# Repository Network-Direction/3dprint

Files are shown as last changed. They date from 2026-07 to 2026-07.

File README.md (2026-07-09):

# 3dprint
My repository of 3d printing information and models.

This is focused on the Ender 3 v3, but would be helpful for other printers too.

</br></br>
## Klipper

Information about using Klipper, including how to connect a Raspberry Pi to the printer, and flash it with Klipper firmware.

</br></br>
## Calibration

Calibrating and tuning Klipper settings for the best prints.

</br></br>
## Macros

Macros used in Klipper or Octoprint.

</br></br>
## Models

Useful models, including Autodesk Fusion source files.

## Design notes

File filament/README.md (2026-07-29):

# Filament Guides

This section includes settings for various filaments I have used, that I have found useful.

These can be a guide to get started, but should not be a replacement for [proper calibration](../calibration).

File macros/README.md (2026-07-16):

# Macros

Macros are a script of g-code to run common commands. For example:
* Commands to run before a print job
* Commands to run after a job completes
* Extrude a test line before starting
* Load or unload filament

</br></br>
---
## Calling Macros from Orca

Macros can be called automatically by referring to them in the gcode. This means the slicer needs to be aware of the macros so it can embed these commands.

In Orca slicer, edit the printer settings, and go to the **Machine G-code** tab.

This contains an area when you can add custom G-code at various points of the print. The two most useful ones are:
* Machine start G-code
* Machine end G-code

</br></br>
These areas run specific commands every time a job starts and ends.

In **Machine start G-code**, replace anything that's already there with:

```gcode
SET_PRINT_STATS_INFO TOTAL_LAYER_COUNT=[total_layer_count]
START_PRINT BED_TEMP=[first_layer_bed_temperature] EXTRUDER_TEMP=[first_layer_temperature]
```

</br></br>
This adds some useful information to the gcode file about the print, such as the total layer count.

The second line is the important one. This calls the [`START_PRINT`](print_start.cmd) macro, and passes the bed and extruder temperature.

> [!WARNING]
> Make sure these macros exist in mainsail if you're going to use them.

</br></br>
In **Machine end G-code**, replace anything that's already there with:

```gcode
END_PRINT
```

</br></br>
This simply calls the [`END_PRINT`](print_end.cmd) macro at the end of a print job.

</br></br>
---
## Macro File

Macros can be placed directly in `printer.cfg`, but it is recommended to put them in a separate file, `macros.cfg`.

The `printer.cfg` file should 'include' this extra file.

```ini
[include macros.cfg]
```

</br></br>


Mainsail includes a macro section on the dashboard containing any macros that have been defined.

These include the ones in `macro.cfg`, as well as some predefined ones from `mainsail.cfg`.

</br></br>
---
## Macro Format

### Starting a Macro

Macros all start with a line like this:

```ini
[gcode_macro MACRO_NAME]
```

This identifies the following code as being a macro, as well as giving it a name.

</br></br>
All macros must also have a line like this:

```gcode
gcode:
  ; Commands
```

This defines the start of the g-code. Commands listed under this must be indented (similar to a YAML file).

</br></br>
### Macro Code

Code within the macro can be:
* Jinja2 template code
* G-code
* Klipper commands
* Calls to other macros

For example, this clears the current state (a klipper command), and then heats the print bed:

```gcode
[gcode_macro EXAMPLE]
gcode:
    CLEAR_PAUSE         ; Klipper command
    M190 S60            ; gcode
```

</br></br>
### Arguments

Arguments can be provided to macros. For example, if we want to preheat the extruder, we can include a temperature to preheat it to.

This is done using a combination of jinja2 and `params`.

```gcode
[gcode_macro PREHEAT]
gcode:
    {% set extruder_temp = params.TEMP | default(220) | float %}
    M104 S{extruder_temp}
```

</br></br>
In this example we can see:
* The macro takes an argument called `TEMP`
* This is an optional argument, as it has a default value
* The datatype for the argument is a `float`
* This value is assigned to the `extruder_temp` variable
* The `M104` command uses the `extruder_temp` variable to preheat the extruder

</br></br>
To use arguments, call a macro like this:

```ini
PREHEAT TEMP=200
```

</br></br>
This calls a macro caled `PREHEAT`, and passes the value `200` as the `TEMP` argument.

</br></br>
### Flow Control and Variables

Flow control, like if, then, else, as well as looping, can be implemented using Jinja2.

Variables can be defined before the `gcode` area, or set within the `gcode` area using jinja templates.

```gcode
[gcode_macro HELLO_BED]
variable_greeting_temp: 40      # Variable set BEFORE gcode:
gcode:
    {% set bed_temp = printer.heater_bed.temperature %}   ; Variable set WITHIN gcode:

    {% if bed_temp > greeting_temp %}
        { action_respond_info("Bed is warm!") }
    {% else %}
        { action_respond_info("Bed is cool.") }
    {% endif %}
```

The example above:
* Sets a variable called `variable_greeting_temp` and sets it to 40
* Gets the current bed temperature, and assigns it to the `bed_temp` variable
* Uses an if/else block to print a message based on the bed temperature

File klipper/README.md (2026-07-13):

# Klipper Guide

The files in this section contain the guide to setup your printer with Klipper, and to connect a slicer to it.

Start with [the Klipper guide](klipper.md) and then move on to [the slicer configuration](orca_setup.md).

Optionally you can use [the slicer settings](slicer_settings.md) that I have created, or use your own.

You may also want to try to [restore the LCD screen functionality](ender_screen.md) after the update.

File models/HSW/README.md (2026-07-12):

# Honeycomb Storage Wall (HSW)

This is a collection of models and files related to the project found here: [https://makerworld.com/en/models/22521-honeycomb-storage-wall]

> [!WARNING]
> Be sure to get the tolerance of the printer right before printing any of the wall parts.
>
> If the tolerance is not right, the socket inserts may not fit into the wall correctly. They would need to be scaled down slightly.

</br></br>
---
## Files

Files are available in various formats.

| File Type | Usage |
| --- | --- |
| stl | The raw model. Will need to be added to a slicer |
| 3mf | A slicer project file. Uses settings suitable for an Ender 3  |
| f3d | An Autodesk Fusion file. So you can edit the designs yourself |

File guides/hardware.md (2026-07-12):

# Hardware

## Nozzle HRC

HRC is the Rockwell Hardness Scale. This measures the hardness of metal materials.

Different nozzles are needed depending on the abrasiveness of the filament. More abrasive filaments will wear down softer nozzles faster.

</br></br>
| Value | Nozzle Type | Filament Type |
| ----- | --- | --- |
| 0 | Brass | PLA, PETG |
| 1 | Coated | Wood filled PLA, Glow in the dark PLA |
| 2 | Hardened Steel | Carbon fiber, metal filled filaments  |
| 3 | Hardened Steel (HRC 60+) | Carbon fiber, metal filled filaments  |

</br></br>
This is set in the filament profile in the slicer, so the slicer knows what nozzle is required. If you use a printer with a softer nozzle, it will warn you about this before you proceed.

A value of zero means this will not be checked.

</br></br>
> [!NOTE]
> Changing this setting will not improve performance or quality. It simply enables your slicer to warn you if needed.

</br></br>
---
## Fans (Ender 3 v3)

The Ender 3 has a total of four fans:
* Hot end cooling fan
* Part cooling fan
* Motherboard fan
* PSU fan

</br></br>
> [!WARNING]
> The Ender uses 24v for fans. Make sure any replacement is 24v as well.
>
> Alternatively, use a 12v fan (quieter) with a _buck converter_ to convert the 24v to 12v.

</br></br>
### Hot End Cooling Fan

This fan is in the extruder, and turns on when printing starts.

It is a 24v 4010 axial fan (40x40x10mm), with 2-pin 1.35mm JST header. 2-pin means there's no PWM, so no control over fan speed. It is on or off.

</br></br>
Good options seem to include:
* Noctua NF-A4x10 FLX (12v, requires buck converter)
* Sunon 4020

</br></br>
### Part Cooling Fan

This is also housed in the extruder. This is PWM controlled, so the printer can control the fan speed.

This is a 24v blower/radial fan, with 1.25mm JST headers. This is still a 2-pin connector. The motherboard uses PWM to control the speed.

Because of the PWM control, any replacement should also be 24v, not 12v with a buck converter.

Typically a new fan shroud would be needed.

</br></br>
> [!WARNING]
> Due to the heat produced, this should be printed in PETG, not PLA.

</br></br>
### Motherboard Fans

This is for cooling the stepper motor drivers. This is a 6015 axial fan (60x60x15mm), at 24v.

Quiet fans to replace this are rare, so the alternative is to adapt the base cover of the printer, and include a larger quiet 12v fan with a buck converter.

</br></br>
### PSU Fan

This is also a 6015 24v axial fan. This keeps the power supply cool. It usually kicks in when the bed warms up.

</br></br>
> [!WARNING]
> Be careful when modifying anything related to the PSU. There is a risk of electrical shock.

</br></br>
Modifying this directly has risks, and voids warranty.

An alternative is to print a new shroud for the PSU, and use large quiet PC fans. These move a lot more air at a lower dB.

</br></br>
### References

https://www.reddit.com/r/ender3/comments/gkkli3/quieting_my_ender_3_pro/

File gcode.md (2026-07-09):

# G Code

## Overview

The programming language that tells the printer what to do. This is similar to assembly code in some ways.

This is the language of machines in general, such as CNC machines, laser cutters, and engravers. It's not just for 3d printers.

You don't generally need to write your own g-code. However, knowing the basics helps when it comes to using macros, and sometimes with troubleshooting.

> [!NOTE]
> There are some differences in gcode between CNC machines and 3d printers.
> This article is only for 3d printers.

</br></br>
### Commands
G-codes start with a letter like 'G' or 'M'.

Some commands take an extra parameter, which also starts with a letter. For example, `M104 S210`

</br></br>
### Parameters

Letters like 'S', 'T', 'V', and others are used as arguments to a command to set values.

For example, in `M104 S210`, the 'm104' part is the command to heat the nozzle. The 'S210' is the temperature to set it to.

Here are some of the letters and what they are for. The 'name' is sometimes historical, and doesn't always accurately represent the use on a 3d printer.

</br></br>
| Letter | Name | Usage |
| --- | --- | --- |
| S | Speed | Sets temperatures or fan speeds |
| X | Coordinate | An X target coordinate |
| Y | Coordinate | A Y target coordinate |
| Z | Coordinate | A Z target coordinate |
| F | Feedrate | Usually the speed the print head moves at |
| E | Extrude | Used with extruder commands. Defines how much filament to extrude |

</br></br>
## Commands

### Geometric Commands

Geometric commands control the motion and positioning of the printer's nozzle. These commands start with a 'G', and are followed by a number.

</br></br>
#### Move - G0 and G1

These are linear movement commands. It tells the print head where to go, using X, Y, Z coordinates, and what speed to move at. The print head will move there in a straight line.

`G0` is a _rapid move_, while `G1` is a _controlled move_. In modern 3d printing, they functionally the same thing.

</br></br>
**Arguments:**

| Argument | Description |
| --- | --- |
| `X` | The X coordinate posistion |
| `Y` | The Y coordinate posistion |
| `Z` | The Z coordinate posistion |
| `F` | Speed of the print head move in mm/min |
| `E` | The amount of filament to extrude |

</br></br>
Not all coordinates are needed, only the ones that are changing.

</br></br>
**Example**

```gcode
G1 X100 Y50 Z0.2 F1500 E5    ; Move to 100,50,0.2 at a rate of 1500mm/min, and extrude 5mm of filament
```

</br></br>
A negative value on `E` will retract the filament:

```gcode
G1 E-1.0 F2100                ; Retracts 1mm of filament
```

</br></br>
#### Dwell - G4

Pauses the command queue, and waits for a period of time. With no arguments, this is the same as `M400`, which causes g-code processing to pause until all other commands are complete (eg, waits for heating or cooling)

</br></br>
**Arguments:**

| Argument | Description |
| --- | --- |
| `S` | Number of milliseconds to dwell |
| `P` | Number of seconds to dwell |

</br></br>
If both arguments are supplied, `S` will take precedence.

</br></br>
#### Home Position - G28

Tells the printer to move the print head back to the home coordinates.

Often this needs to be done before other operations can be started.

</br></br>
#### Positioning - G90 and G92

`G90` sets absolute positioning mode. This means the printer will move exactly to the given coordinates. It will not move relative to its current position.

`G92` tells the printer to rename the current position as _zero_. This is like telling the printer where to start from.

</br></br>
**Example**

```gcode
G92 E0    ; Reset the extruder's position reference, and extrude nothing
```

</br></br>
### Miscellaneous Commands

These commands are for non-geometric tasks. They all start with the letter 'M', followed by a number.

Some of these commands need to complete before moving to the next command. Others start the command and move on immediately.

</br></br>
#### Relative Mode - M83

Sets the extruder to _relative_ mode. The extruder is also known as the **E-Axis**.

This means each extrusion commands will just extrude the amount of filament they're told to in the instruction, not work on a cumulative total.

</br></br>
#### Disable Motors - M84

Turns the motors off, typically when a print job has been completed.

</br></br>
#### Nozzle Temperature - M104 and M109

Both of these will set the nozzle temperature.

`M104` will set the temperature, and let the printer move on to the next command while the hot end heats up.

`M109` requires the hot end to heat up to the given temperature before the printer moves on to the next command.

</br></br>
**Arguments:**

| Argument | Description |
| --- | --- |
| `S` | The temperature to set |

</br></br>
**Example**

```gcode
M104 S220
```

</br></br>
#### Bed Temperature - M140 and M190

Both set the bed temperature. 

`M140` will set the temperature, and let the printer move on to the next command while the hot end heats up.

`M190` requires the bed to heat up to the given temperature before the printer moves on to the next command.

</br></br>
**Arguments:**

| Argument | Description |
| --- | --- |
| `S` | The temperature to set |

</br></br>
**Example**

```gcode
M104 S220
```

</br></br>
#### Acceleration - M204

Sets the preferred acceleration of the hotend.

</br></br>
#### Cancel Objects - M486

Used to cancel specific items on the print bed. When printing multiple items at once, you may want to cancel one of them without cancelling the entire print job. This command can do this.

To support this, the slicer needs:
* Label Objects:    Enabled
* Exclude Objects:  Enabled

</br></br>
**Arguments:**

| Argument | Description |
| --- | --- |
| `C` | Cancel the current object |
| `P<index>` | Cancel an object with a given index |
| `S<index>` | Set the index of the current object |
| `T<index>` | Reset state and set the number of objects |
| `U<index>` | Un-cancel object with the given index |

</br></br>
### Ignored Commands

The slicer will create a gcode file which is sent to the printer for processing.

The Klipper firmware will ignore some of the codes, as it does not use them.

These include:
* M201
* M203
* M205

</br></br>
---
## References

Gcodes can be found here: [https://marlinfw.org/docs/gcode/G004.html]

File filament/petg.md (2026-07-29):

# PETG Filament Settings

Useful settings I have found. Tested on the Ender 3 v3 SE with unicorn hotend.

> [!WARNING]
> This page is stil in progress

</br></br>
---
## Process Settings

</br></br>
| Tab | Section | Setting | Value |
| --- | --- | --- | --- |
| Quality | Precision | X-Y Hole Compensation | 0.17mm |
| Quality | Precision | X-Y Contour Compensation  | |

</br></br>
| Tab | Section | Setting | Value |
| --- | --- | --- | --- |
| Speed | First Layer Speed  | First layer | 30mm/s |
| Speed | First Layer Speed  | First layer infill | 40mm/s |
| Speed | First Layer Speed  | First layer travel speed  | 100mm/s  |
| Speed | Other Layers Speed | Outer wall | 100mm/s  |
| Speed | Other Layers Speed | Inner wall | 120mm/s  |

</br></br>
---
## Basic PETG

Tested using Bambu Labs Basic PETG.

</br></br>
### Filament Settings

| Tab | Section | Setting | Value |
| --- | --- | --- | --- |
| Filament | Basic | Shrinkage (XY) | 100% |
| Filament | Basic | Shrinkage (Z) | 100% |
| Filament | Basic | Min nozzle temp | 230 |
| Filament | Basic | Max nozzle temp | 260 |
| Filament | Flow and PA | Flow Ratio | 0.93 |
| Filament | Flow and PA | Pressure Advance | Disabled |
| Filament | Print Temp  | Nozzle: First Layer  | 260 |
| Filament | Print Temp  | Nozzle: Other Layers | 245 |
| Filament | Bed Temp | Textured PEI | 80 |
| Filament | Volumetric  | Max vol speed | 14.9 |

</br></br>
| Tab | Section | Setting | Value |
| --- | --- | --- | --- |
| Cooling  | Cooling for Layer | No cooling for first | 3 layers |
| Cooling  | Part Cooling Fan  | Min fan speed threshold | 20% |
| Cooling  | Part Cooling Fan  | Max fan speed threshold | 40% |

</br></br>
| Tab | Section | Setting | Value |
| --- | --- | --- | --- |
| Overrides | Retraction | Length | 1.2mm |

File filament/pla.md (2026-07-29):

# PLA Filament Settings

Useful settings I have found. Tested on the Ender 3 v3 SE with unicorn hotend.

</br></br>
---
## Process Settings

</br></br>
| Tab | Section | Setting | Value |
| --- | --- | --- | --- |
| Speed | First Layer Speed  | First layer | 30mm/s |
| Speed | First Layer Speed  | First layer infill | 40mm/s |
| Speed | First Layer Speed  | First layer travel speed  | 100mm/s  |
| Speed | Other Layers Speed | Outer wall | 140mm/s  |
| Speed | Other Layers Speed | Inner wall | 160mm/s  |

</br></br>
> [!NOTE]
> These next settings will vary per printer. See the [calibration guides](../calibration) to tune them.

</br></br>
| Tab | Section | Setting | Value |
| --- | --- | --- | --- |
| Quality | Line width | First layer | 125% |
| Quality | Precision | X-Y hole compensation | 0.12mm |
| Quality | Precision | X-Y contour compensation  | 0.2mm |
| Quality | Walls and Surfaces | Bottom surface flow ratio | 1.02 |

</br></br>
---
## Basic PLA

Tested using Bambu Labs Basic PLA.

</br></br>
### Filament Settings

| Tab | Section | Setting | Value |
| --- | --- | --- | --- |
| Filament | Basic | Shrinkage (XY) | 100% |
| Filament | Basic | Shrinkage (Z) | 100% |
| Filament | Basic | Min nozzle temp | 190 |
| Filament | Basic | Max nozzle temp | 240 |
| Filament | Flow and PA | Flow Ratio | 0.98 |
| Filament | Flow and PA | Pressure Advance | Disabled |
| Filament | Print Temp  | Nozzle: First Layer  | 220 |
| Filament | Print Temp  | Nozzle: Other Layers | 220 |
| Filament | Bed Temp | Textured PEI | 60 |
| Filament | Volumetric  | Max vol speed | 18.81 |

</br></br>
---
## Matte PLA

Tested using Sunlu Matte PLA.

</br></br>
### Filament Settings

| Tab | Section | Setting | Value |
| --- | --- | --- | --- |
| Filament | Basic | Shrinkage (XY) | 100% |
| Filament | Basic | Shrinkage (Z) | 100% |
| Filament | Basic | Min nozzle temp | 205 |
| Filament | Basic | Max nozzle temp | 245 |
| Filament | Flow and PA | Flow Ratio | 0.97 |
| Filament | Flow and PA | Pressure Advance | Disabled |
| Filament | Print Temp  | Nozzle: First Layer  | 220 |
| Filament | Print Temp  | Nozzle: Other Layers | 210 |
| Filament | Bed Temp | Textured PEI | 60 |
| Filament | Volumetric  | Max vol speed | 18.81 |

</br></br>
| Tab | Section | Setting | Value |
| --- | --- | --- | --- |
| Overrides | Retraction  | Length | 0.4mm |
| Overrides | Retraction  | Retraction Speed | 45mm/s |
| Overrides | Retraction  | Deretraction Speed | 35mm/s |
| Overrides | Retraction  | Retract on Layer Change | Enabled  |
| Overrides | Retraction  | Wipe while retracting | Enabled  |
| Overrides | Retraction  | Wipe distance | 1mm |
| Overrides | Retraction  | Amount before wipe | 70% |

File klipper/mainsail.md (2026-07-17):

# Mainsail Tools and Customizations

## Macros

There are several [macros](../macros.README.md) which are included by default, and of course, we can add our own. These show up in a panel on the dashboard:



</br></br>
### Hiding Macros

That's a bit cluttered though. There's some macros there we use regularly, some occasionally, and some that we never touch manually.

To tidy this up, go to **Interface Settings**, then to the **Macros** tab.

Here, we can toggle which macros are visible, and which aren't. This is useful to hide things like `END_PRINT`, which is called automatically at the end of a print, not manually.



</br></br>
### Grouping Macros

We can take this one step further and group macros into categories. In the **Macros** settings, change the **Management** type to **Expert**.

This will change the view to include _Groups_. There are none by default, so click **Add Group**.

Now give the group a name. I'm going to create one for **Calibration**. Under **Status** I'm going to click the 3rd button to hide this group while the printer is active.

Next, I'll add the **PID_BED** and **PID_EXTRUDER** macros to this group.



</br></br>
Repeat this to create more groups as you need to.

</br></br>
---
## Presets

At the top of the **Temperatures** panel you will see _Cooldown_. This is a preset, and the only one that's there by default.



</br></br>
Let's add another one. Go to **Interface Settings**, then to the **Presets** tab.

If you edit the existing _Cooldown_ macro, you will see that it contains `TURN_OFF_HEATERS` as custom G-Code. You can tune this if you want to.

Let's add a new preset called **Preheat**. For this, I will set the _Extruder_ to 220, and the _Heater Bed_ to 60.

The _Temperatures_ dashboard now has a drop-down called **Presets**, which contains the _cooldown_ and _preheat_ presets.

</br></br>
---
## Toolhead Position

The toolhead panel in the dashboard lets us control the position of the toolhead, both while the printer is idle, and while it is printing.

</br></br>
### Idle Printer

While the printer is idle, we can use buttons to move the toolhead. The home button sends a `G28` code to move the toolhead to the home position.

The 'disable motors' button turns off the stepper motors, so we can physically move the print head. Useful for maintenance on the printer.

The three bars following that lets us move the print head to different locations. I like using the '+25' button on the Z-axis to raise the tool head so I can get access to the nozzle for cleaning.

</br></br>
### Print in Progress

Here is the toolhead panel while printing is in progress:



</br></br>
We can finetune the Z-Offset while printing here, to test different heights in real time.

We've also got the option to slow down or speed up the print using the speed factor setting.

The top of the panel shows some information about current settings. The `position` is set to `absolute`. This will have been set using a `G90` code within the gcode file or in a start print macro.

The `adaptive-` part shows the bed mesh profile that was loaded. In this case, it was set dynamically as part of the print job.

</br></br>
### Customization

To customize, click the gears in the top right of mainsail to get the _Interface Settings_ window. Then go to _Control_.

Optionally change the style of the panel:



</br></br>
Additionally, you can change the buttons available to move the toolhead. For example, you may want an option to move the Z-axis up by 100mm.



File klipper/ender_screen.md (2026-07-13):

# Restoring the Ender Screen

## Overview
After upgrading the firmware to Klipper, the default screen will no longer work. It is proprietary, and does not work with Klipper natively.

There are three options from here:
1. Don't use it at all, and just use Mainsail
2. Use a different screen with KlipperScreen
3. Restore some of the functionality to the stock screen

</br></br>
This guide is about restoring the sceen functionality (option #3).

The idea behind this is to replace the Klipper firmware with a customised firmware that knows how to 'talk' to the screen.

</br></br>
> [!NOTE]
> Not all features are fully restored.

</br></br>
## Process

This is based on this project: https://github.com/jpcurti/ender3-v3-se-klipper-with-display

</br></br>
> [!WARNING]
> This project assumes the LCD screen is running firmware version 1.0.6

</br></br>
### Part 1 - Build the Firmware

1. SSH to the Raspberry Pi
2. Clone the project (commands below)
3. Run `make menuconfig`
4. Use the same settings you used [during the normal Klipper installation](klipper.md)
5. Enable **extra low level configuration** options
6. Enable **Serial Bridge**
7. Enable **USART2**
8. Save and quit
9. Run `make` to build the firmware as a binary

</br></br>
```bash
git clone https://github.com/jpcurti/ender3-v3-se-klipper-with-display
cd ender3-v3-se-klipper-with-display
make menuconfig
```

</br></br>
### Part 2 - Flash the Printer

This part is the same as a regular Klipper firmware flash. To summarise:

1. Rename the existing `klipper.bin` file
2. Copy the new `klipper.bin` from the `out` directory to the printer's config directory
3. From Mainsail, download the new binary
4. Place the binary on the SD Card
5. Proceed to flash the printer as normal

</br></br>
```bash
mv ~/printer_data/config/klipper.bin ~/printer_data/config/klipper_vanilla.bin
cp ~/ender3-v3-se-klipper-with-display/out/klipper.bin ~/printer_data/config/
```

</br></br>
> [!NOTE]
> Refer to the FAQ on the project repository if you have issues.

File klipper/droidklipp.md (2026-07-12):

# DroidKlipp and KlipperScreen

## Overview

KlipperScreen is the module that lets you connect a touch screen to Klipper, for local control and monitoring.

Example hardware [can be found here](https://klipperscreen.readthedocs.io/en/latest/Hardware/)

</br></br>
If you don't have one of these screens, another option is to use an old Android device to be your screen.

This uses **XServer-XSDL** on the Raspberry Pi. The phone is connected to the RPi with a USB cable (or optionally a WiFi connection) using [ADB](https://developer.android.com/tools/adb).

Klipper includes [documentation](https://klipperscreen.readthedocs.io/en/latest/Android/) of how this works, and how you can set it up.

</br></br>
A potentially easier option is to use [DroidKlipp](https://github.com/CodeMasterCody3D/DroidKlipp). It manages many of the settings for you.

</br></br>
---
## Process

Here is the high-level process I used to get this working:

1. Unlock the phone and install LineageOS (Optional)
2. Installed DroidKlipp through an APK file
3. Install KlipperScreen and DroidKlipp on the Raspberry Pi
4. Connected the Phone to the RPi, and customised

</br></br>
### Lineage OS

This is an optional step. In my case, I unlocked the bootloader of my old phone, and installed [Lineage OS](https://lineageos.org/).

I did this so I could have a very lightweight setup on the phone. I didn't install any Google apps at all.

How this is done will depend on the device that you want to use. The basic idea is to flash the phone with a lineage recovery image, and let it install.

I'll leave you to investigate the details of how this is done yourself.

</br></br>
### Phone Setup

A mandatory step is to enable USB debugging. To do this, first enable developer mode:

1. Open Settings > About Phone > Software Information
2. Tap the build number 7 times

</br></br>
Now to enable USB debugging;

1. Settings > Developer mode
2. Find USB debugging, and toggle the slider

</br></br>
While you're there, there are some other options that will help (but aren't mandatory):

* Enable _don't keep activities_ (in developer options)
* Limit background processes to 2 (also in dev options)
* Remove the lock screen, so you don't need to unlock the device each time

</br></br>
### DroidKlipp App

[Download the DroidKlipp APK](https://github.com/CodeMasterCody3D/DroidKlipp-Android-APK/releases/latest/download/DroidKlipp.apk) from the [GitHub page](https://github.com/CodeMasterCody3D/DroidKlipp).

Transfer this to your device, and install it as normal.

</br></br>
### Raspberry Pi Setup

To setup the Raspberry Pi, you will need to [run KIUAH](klipper.md) again. Make sure there's no print job running while installing apps.

1. Install KlipperScreen
  1. Use 'standalone mode'
  2. Use **X11** as the server (**Wayland** is not supported yet)
  3. Do not install **Network Manager**

2. Install DroidKlipp
  1. Get this from the _extensions_ area
  2. When asked, skip configuring a manual IP

</br></br>
### Connection and Customization

Connect the phone:

1. Launch the DroidKlipp app on the phone
2. Follow the prompts to set the screen resolution, etc
3. Connect the phone to the RPi with a USB cable
4. Confirm that you have access to the printer

</br></br>
Customization is optional. The default settings work just fine.

However, to customise, follow this process:

1. Restart the KlipperScreen service (use the 'power button' in mainsail)
2. Confirm that a `KlipperScreen.conf` file has been created (it will be empty)
3. Refer to [the documentation](https://klipperscreen.readthedocs.io/en/latest/Configuration/) to see configuratble settings

</br></br>
Sample configuration:

```ini
# ===============================================
# Interface settings
# ===============================================

[main]
# Interface theme
# Options: default, material-dark, colorized, voron-dark
# voron-dark hides some icons and menu items
# default, material-dark, and colorized are very similar
theme = colorized

# Job status timeout after a job (0 is disabled)
job_complete_timeout: 0
job_error_timeout: 0

# Autolock screen (0 is disabled)
autolock_timeout: 0
start_locked: False

[printer Ender]
# Information displayed in the titlebar
# Options: full, short, None
titlebar_name_type: full

# Items in the titlebar, in addition to extruder and bed temp
titlebar_items: None

# ===============================================
# Extra menu items
# ===============================================

[menu __main homing]
name: Home
icon: home
method: printer.gcode.script
params: {"script":"G28"}

#~# --- Do not edit below this line. This section is auto generated --- #~#
#~#
#~# [main]
#~# theme = colorized
#~#
```

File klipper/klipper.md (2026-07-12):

# Klipper and Raspberry Pi

## Overview

The Ender 3 comes with the Marlin firmware. Many printers now come with the Klipper firmware, because it's just awesome.

This guide is about installing the Klipper firmware on the Ender 3, and controlling it over the network via a Raspberry Pi rather than needing an SD-CARD. That means we can print straight from the slicer, just like the rich people with fancy printers do.

Most of this is based around [https://athemis.me/projects/klipper_guide/]. There's just a few things I learned along the way that will help.

</br></br>
> [!WARNING]
> A result of this process is the LCD control screen is disabled.</br>
> 
> Some limited functionality can be restored, but it won't be the same as before.
> 
> The web interface is used as a replacement for this

</br></br>
The end result will be:
* A Raspberry Pi (RPi) will be connected to the printer with a USB-C cable
* The RPi will be connected to the network (wired or wireless)
* The printer will run Klipper firmware
* The slicer will see the RPi as the printer, and send prints there

</br></br>
---
## Components

### Hardware

In terms of hardware, all you need is:
* A Raspberry Pi (I used a Pi 4)
* Power for the RPi
* A microSD card for the RPi
* Your usual SD-Card for the printer
* A USB-C cable to connect the RPi to the printer

</br></br>
### Software

There are several software components this project will use, as outlined below.

**KIAUH** - A script used for setting up the environment, and installing other components.

**Klipper** - The firmware that the printer will run.

**Moonraker** - The API that lets us interact with the Klipper firmware.

**Mainsail** - The web GUI that we access (fluidd is an alternative).

</br></br>
---
## Process

### Step 1 - Set up the RPi

1. Download and install the Raspberry Pi Imager tool
2. Run the tool, and select your model of RPi
3. Select the 64-bit Raspberry Pi OS, Lite edition, as the operating system
4. Work through the wizard, entering your username, password, WiFi credentials, and hostname
5. Make sure you have SSH enabled
6. Write the OS to the SD Card
7. Start the RPi up and confirm you can SSH to it

</br></br>
### Step 2 - KIAUH

Install the KIAUH script, which will manage the install of everything else.

```bash
sudo apt update && sudo apt upgrade -y
sudo apt install git -y
cd ~ && git clone https://github.com/dw-0/kiauh.git
```

</br></br>
### Step 3 - Install Other Components

Start the KIAUH script:

```bash
./kiauh/kiauh.sh
```


</br></br>

1. Go to 'install'
2. Install Klipper
3. Install Moonraker
4. Install Mainsail

</br></br>
---
## Configuration Files

Open a web browser and navigate to http://IP-of-your-RPi

You will see a dashboard with some error messages. These errors are because the printer is not connected yet.

</br></br>
There will be several configuration files that we will need to work with. These are present regardless of which UI (mainsail or fluidd) you choose to use.

The main ones are:

**printer.cfg** - Configuration for Klipper running on the printer.

**macro.cfg** - A collection of macros, which are a collection of g-code commands to make some tasks easier.

**mainsail.cfg** - Mainsail UI configuration, as well as some built in macros we can use for things like calibration.

**moonraker.conf** - Settings for the moonraker API.

</br></br>
Mostly we will work with `printer.cfg` and `macros.cfg`.

</br></br>
In the mainsail UI, click the 'Machine' tab on the left. This will show you a list of config files.

`printer.cfg` and `macros.cfg` should already be there.

However, we want to replace these with the ones found here: [https://github.com/shubham0x13/ender-3-v3-se-klipper-config].

These are already tuned for the Ender 3 printer. Download them, and replace the existing files with these.

</br></br>
---
## Klipper Firmware

Now to create the custom Klipper firmware that will be installed on the printer.

We generate this on the RPi, and then flash the printer through the standard SD Card.

</br></br>
### Create Firmware

First, SSH to the RPI, and run `menuconfig` from the klipper directory (within your home directory).

```bash
cd ~/klipper
make menuconfig
```

</br></br>
This will start a script that will build the firmware.



</br></br>
The older models are configured as shown in the image above.

For the newer motherboard (the 'CR4NS200320C14'), change these values:
* Processor Model: STM32F401
* Bootloader Offset: 64KiB

</br></br>
Save your changes and quit.

Next, run `make` to build the firmware. This will create a file called `~/klipper/out/klipper.bin`.

Copy this file to the 'config' directory (this is where `printer.cfg` is):

```bash
cp ~/klipper/out/klipper.bin ~/printer_data/config/
```

</br></br>
### Flash the Printer

Go back to the 'Machine' tab in mainsail. `klipper.bin` should be visible in the file list. Download it.

1. Make sure the printer is off
2. Transfer the new firmware to the SD Card
3. Insert the card into the printer, and turn it on
4. Wait for 15 seconds
5. Turn off the printer
6. Remove the file from the SD card and replace
7. Turn on the printer

</br></br>
> [!WARNING]
> Apparently the newer motherboard required the bin file to be in a directory called `STM32F4_UPDATE` on the SD Card.

</br></br>
The LCD panel on the printer will show a default blue image.

</br></br>
### Prepare a USB Cable

There is a catch when using an RPi with your printer. The RPi will supply +5v across the USB port.

The problem is, if the printer is turned off, the RPi will supply the +5v and attempt to power the printer's motherboard.

This creates some weird side effects, and may cause damage.

There are a few solutions:
* Never leave your printer connected to USB when it is off (boo)
* Use a USB-A to USB-C cable, and [tape off the +5v pin on the USB-A End](https://community.octoprint.org/t/put-tape-on-the-5v-pin-why-and-how/13574)
* Modify your cable by cutting the red wire within (the power wire)
* [Printing a shield](https://www.thingiverse.com/thing:3044586) of some sort to block the pin
* Buying a USB power blocker

</br></br>
### Connecting the RPi

Connect the RPi to the printer with the USB cable, and go back to mainsail.

You may need to click **Restart Firmware** to get it to recognise the printer.

</br></br>
> [!NOTE]
> I found that some USB cables wouldn't work. Some may be for charging devices only.
> 
> If you have troubles, try changing cables. I have found that USB-C to USB-C cables are best. Try using a USB-A to USB-C converter on the RPi end.
> 
> Also see [USB Troubleshooting](usb_tshoot.md)

</br></br>
### Testing

The firmware is installed on the printer, and the software is now ready to go.

A Simple way to test it is working is to click the home button in the 'Toolhead' area.



</br></br>
> [!NOTE]
> Now you're running Klipper, you don't need the SD Card for regular operation.
>
> However, you might need it in future if you need to flash the firmware again.

</br></br>
---
## Next Steps

Now that's done, your next steps are:
* Calibrate the printer
* Learn about Macros
* Configure the slicer

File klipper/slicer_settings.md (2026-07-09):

# Slicer Settings

The settings here are useful to have as defaults. Some of these are for supporting Klipper specfically, while others are just plain good.

These can apply to any slicer, but I've been using Orca.

</br></br>
---
## Filament Settings

Filament settings will vary depending on the filament you use (duh).

However, I recommend disabling **pressure advance**, as this is better managed in Klipper.

</br></br>
If you're interested, here are some settings I used for Sunlu Matte PLA:

| Area | Category | Setting | Value |
| --- | --- | --- | --- |
| Filament | Basic Information | Recommended nozzle temp (min) | 205° |
| Filament | Basic Information | Recommended nozzle temp (max) | 245° |
| Filament | Flow Ratio & Pressure Advance | Flow ratio | 0.95 |
| Filament | Flow Ratio & Pressure Advance | Pressure Advance | Disabled |
| Filament | Print Temperature | First Layer | 220° |
| Filament | Print Temperature | Other Layers | 220° |
| Filament | Bed Temperature | First Layer | 60° |
| Filament | Bed Temperature | Other Layers | 60° |

</br></br>
---
## Process Settings

These are in the slicer, over on the left, under the _Printer_ and _Filment_ settings.



</br></br>
### Quality

_Default settings are fine_

</br></br>
### Strength

| Section | Setting | Value  |
| --- | --- | --- |
| Infill  | Sparse infill pattern | Gyroid |

</br></br>
### Speed

| Section | Setting | Value |
| --- | --- | --- |
| First Layer  | First Layer | 60mm/s |
| First Layer  | Infill | 80mm/s |
| Other Layers | Outer Wall | 140mm/s  |
| Other Layers | Inner Wall | 160mm/s  |
| Acceleration | Normal Printing | 0 |
| Acceleration | accel_to_decel | Disabled |

</br></br>
> [!NOTE]
> Acceleration is disabled here as it is handled by Klipper.

</br></br>
### Support

| Section | Setting | Value |
| --- | --- | --- |
| Support | Enable Support | Enabled |
| Support | Type | Tree (auto) |
| Support | Style | Tree Slim |

</br></br>
### Others

| Section | Setting | Value |
| --- | --- | --- |
| G-Code Output | Label Objects | Enabled |
| G-Code Output | Exclude Objects | Enabled |

</br></br>
> [!NOTE]
> This is to support cancelling single objects, such as with the `M486` command.

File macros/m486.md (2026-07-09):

# M486 - Cancel Objects

## Description

The M486 command cancels specific objects on the build plate, rather than cancelling the entire print job.

This macro handles this instruction gracefully.

</br></br>
## Params

| Param | Description |
| --- | --- |
| `C` | Cancel the current object |
| `P<index>` | Cancel an object with a given index |
| `S<index>` | Set the index of the current object |
| `T<index>` | Reset state, set number of objects |
| `U<index>` | Un-cancel object with the given index |

</br></br>
## Code Flow

Step 1: Check that `exclude_object` is enabled. If not, print an error.

```jinja
{% if 'exclude_object' not in printer %}
  {action_raise_error("[exclude_object] is not enabled")}
{% endif %}
```

</br></br>
Step 2: Check if a reset message has been sent

```jinja
{% if 'T' in params %}
  EXCLUDE_OBJECT RESET=1

  {% for i in range(params.T | int) %}
    EXCLUDE_OBJECT_DEFINE NAME={i}
  {% endfor %}
{% endif %}
```

</br></br>
This loops through the objects in the `T` parameter, and defines a name for each object.

</br></br>
Step 3: Check if a 'cancel current' command has been issued.

```jinja
  {% if 'C' in params %}
    EXCLUDE_OBJECT CURRENT=1
  {% endif %}
```

</br></br>
Step 4: Check if a 'cancel item' command has been issued.

```jinja
{% if 'P' in params %}
  EXCLUDE_OBJECT NAME={params.P}
{% endif %}
```

</br></br>
Step 5: Check if a 'set index' command has been issued

```jinja
{% if 'S' in params %}
  {% if params.S == '-1' %}
    {% if printer.exclude_object.current_object %}
      EXCLUDE_OBJECT_END NAME={printer.exclude_object.current_object}
    {% endif %}
  {% else %}
    EXCLUDE_OBJECT_START NAME={params.S}
  {% endif %}
{% endif %}
```

</br></br>
Step 6: Check if an 'un-cancel' command has been sent

```jinja
{% if 'U' in params %}
  EXCLUDE_OBJECT RESET=1 NAME={params.U}
{% endif %}
```

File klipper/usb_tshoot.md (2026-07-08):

# Troubleshoot USB Connections

If you have problems connecting the RPi to the printer through USB, here are a few things to try.

First, run `lsusb` to check if the device is listed.

```bash
admin@my-rpi:~ $ lsusb
Bus 001 Device 001: ID 1d6b:0002 Linux Foundation 2.0 root hub
Bus 001 Device 002: ID 2109:3431 VIA Labs, Inc. Hub
Bus 001 Device 007: ID 1a86:7523 QinHeng Electronics CH340 serial converter
Bus 002 Device 001: ID 1d6b:0003 Linux Foundation 3.0 root hub
```

</br></br>
We can see it here listed as `QinHeng Electronics CH340 serial converter`.

If it's not there, you could try checking the `dmesg` logs.

```bash
admin@my-rpi:~ $ dmesg | grep usb
[172655.364024] usb 1-1.2: new full-speed USB device number 6 using xhci_hcd
[172655.458174] usb 1-1.2: New USB device found, idVendor=1a86, idProduct=7523, bcdDevice= 2.64
[172655.458203] usb 1-1.2: New USB device strings: Mfr=0, Product=2, SerialNumber=0
[172655.458216] usb 1-1.2: Product: USB Serial
[172655.468513] usb 1-1.2: ch341-uart converter now attached to ttyUSB0
```

</br></br>
The output above shows just part of the logs, focusing on when I connected the USB cable.

This shows that the device is connected, as is represented as `ttyUSB0`.

If you're not seeing this at all, you may want to try some different cables. Some cables don't work. I think some are for charging only and will not carry data.

</br></br>
`/dev/ttyUSB0` is a friendly name that represents the USB device. The thing is, this name can be different each time the device is connected. It may be `/dev/ttyUSB0` one time, or `/dev/ttyUSB1` another time, or some other number.

The friendly name is actually a link (technically a _symlink_) to the real device, which is located at `/dev/derial/by-id`.

We can see the link between the friendly name and the real or _stable_ name like this:

```bash
admin@my-rpi:~ $ ls -l /dev/serial/by-id/
total 0
lrwxrwxrwx 1 root root 13 Jul  9 09:09 usb-1a86_USB_Serial-if00-port0 -> ../../ttyUSB1
```

</br></br>
Here, we see the friendly name is `ttyUSB1`, and the real name is `usb-1a86_USB_Serial-if00-port0`.

Why is this important? Klipper needs to know what USB device is used to connect to the printer. This is in `printer.cfg`, in the `[mcu]` section.

If this uses a friendly name like `ttyUSB1`, it will be _unstable_. That is, if the USB name changes, klipper will no longer be able to connect to the printer.

Instead, make sure you're using the real name of the device.

```ini
[mcu]
serial: /dev/serial/by-id/usb-1a86_USB_Serial-if00-port0
```

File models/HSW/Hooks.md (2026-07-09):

# Hooks

Various hooks that connect to the standard socket.

</br></br>
Front:



</br></br>
Back:



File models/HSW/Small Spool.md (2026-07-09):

# Small Spool

Holds a small spool of something. Perhaps solder or tape.

</br></br>
Front:



</br></br>
Back:



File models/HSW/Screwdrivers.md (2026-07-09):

# Screwdrivers

Holds standard screwdrivers.

</br></br>
Front:



</br></br>
Back:



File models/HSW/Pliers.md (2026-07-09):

# Pliers

Holds small pliers.

</br></br>
Front:



</br></br>
Back:



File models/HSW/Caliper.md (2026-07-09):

# Caliper Holder

Front:



</br></br>
Back:



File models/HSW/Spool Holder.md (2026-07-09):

# Spool Holder

Holds two filament spools directly on the wall.

</br></br>
Top:



</br></br>
Bottom:



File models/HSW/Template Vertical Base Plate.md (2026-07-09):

# Template - Vertical Base Plate

A vertical base plate with three inserts on the back.

Intended to edit to your needs.

</br></br>
Front:



</br></br>
Back:



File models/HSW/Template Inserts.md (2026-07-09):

# Template - Inserts

Template file for the standard socket and insert for the wall.

The socket is inserted into the HSW frame. The insert is added to the socket.

To be useful, the insert will need to be added to some other part.

</br></br>


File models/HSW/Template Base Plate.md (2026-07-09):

# Template - Base Plate

A template that you can edit to add whatever you want.

Includes four inserts on the back.

</br></br>
Front:



</br></br>
Back:



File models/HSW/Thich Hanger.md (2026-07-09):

# Thick Hanger

A hanger with thick hooks.

</br></br>
Front:



</br></br>
Back:



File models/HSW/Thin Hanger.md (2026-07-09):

# Thin Hanger

A hanger with thin hooks.

</br></br>
Front:



</br></br>
Back:



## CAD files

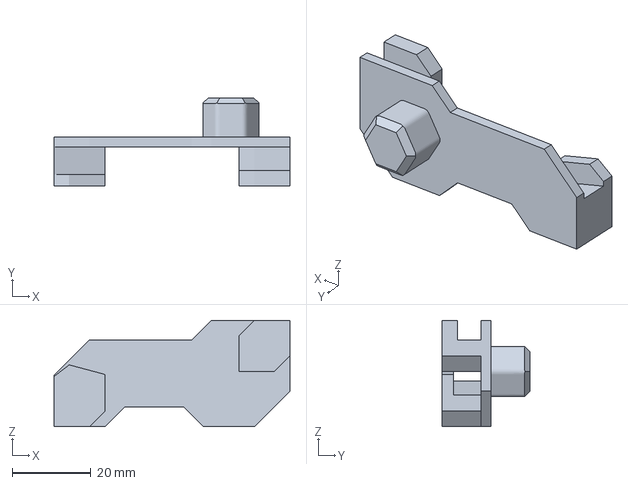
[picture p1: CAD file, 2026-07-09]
models/HSW/Caliper.3mf
60.0 x 22.5 x 27.0 mm

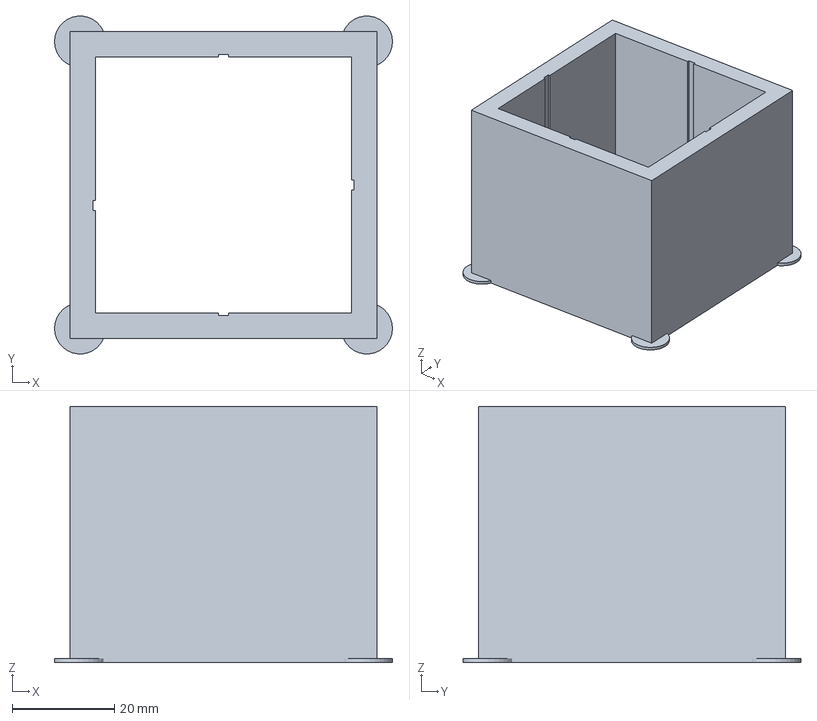
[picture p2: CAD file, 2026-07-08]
models/testing/square_tower.3mf
66.0 x 65.9 x 50.0 mm

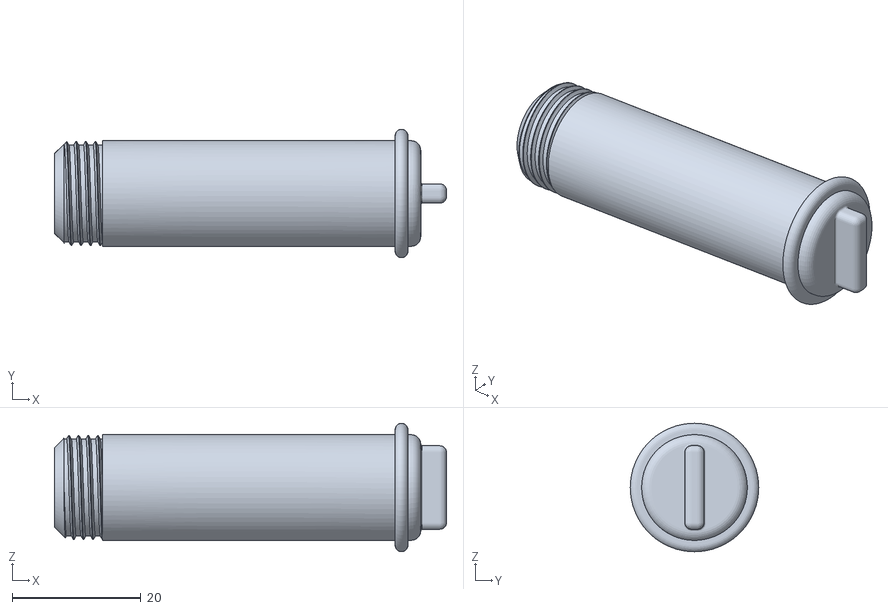
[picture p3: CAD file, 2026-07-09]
models/HSW/Small Spool Shaft.stl
61.0 x 20.0 x 20.0

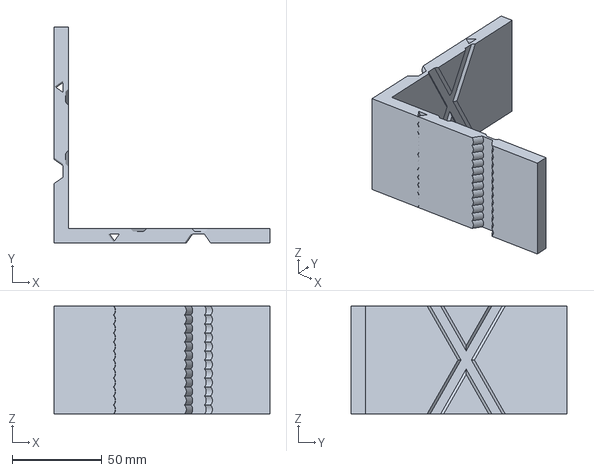
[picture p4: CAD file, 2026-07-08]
models/testing/ringing_tower.3mf
120.0 x 120.0 x 60.0 mm

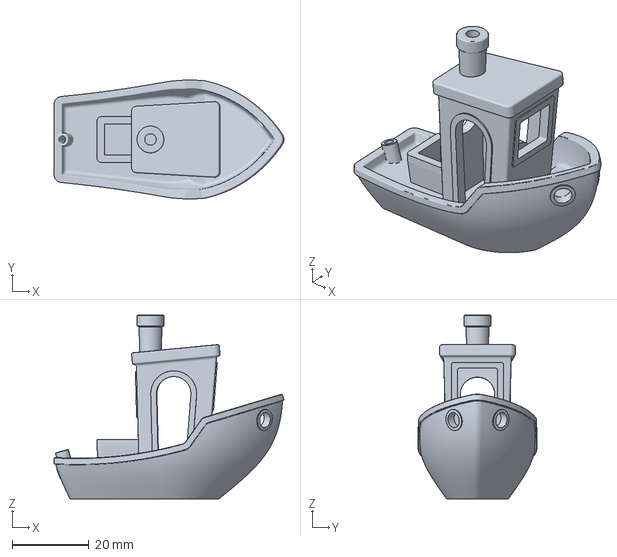
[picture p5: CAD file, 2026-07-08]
models/testing/Benchy.3mf
60.0 x 31.0 x 48.0 mm

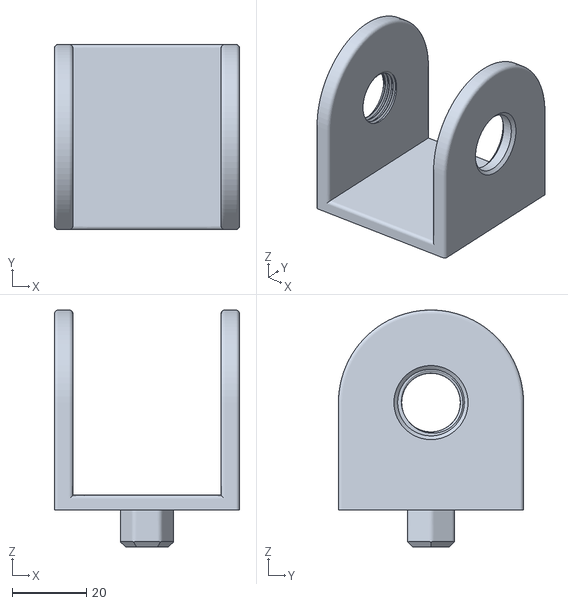
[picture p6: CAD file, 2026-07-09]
models/HSW/Small Spool Chassis.stl
50.0 x 50.0 x 64.0

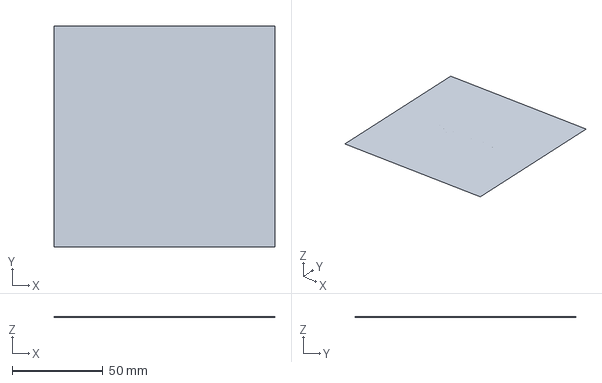
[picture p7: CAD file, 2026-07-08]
models/testing/First Layer Test.3mf
121.8 x 121.8 x 0.127 mm

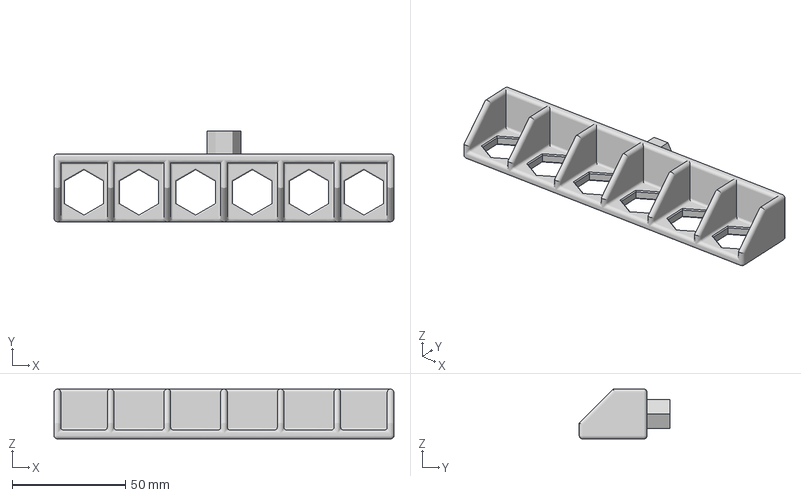
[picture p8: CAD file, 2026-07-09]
models/HSW/Pliers.3mf
150.0 x 40.0 x 22.0 mm

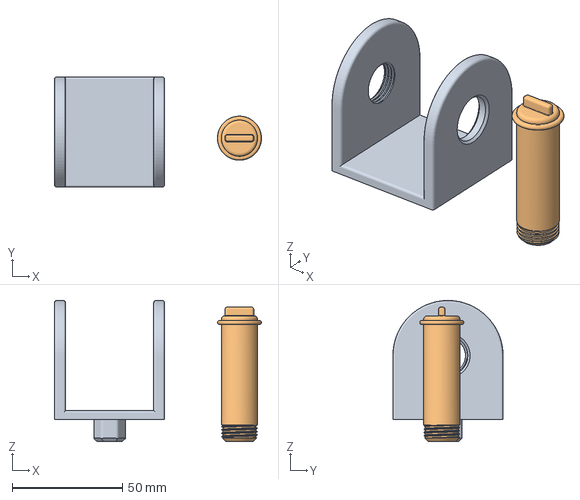
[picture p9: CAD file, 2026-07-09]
models/HSW/Small Spool.3mf
93.9 x 50.0 x 64.0 mm
Small Spool Shaft.stl

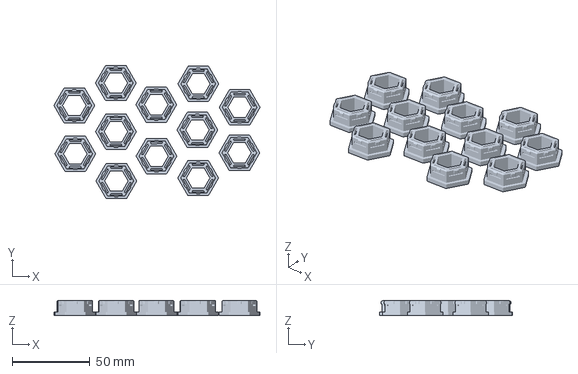
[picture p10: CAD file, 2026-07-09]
models/HSW/Insert Socket.3mf
132.5 x 85.8 x 9.90 mm

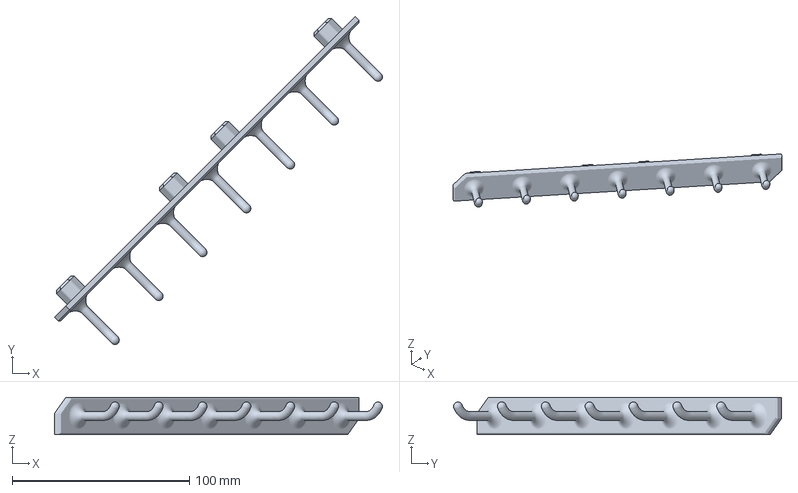
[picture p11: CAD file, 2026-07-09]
models/HSW/Thin Hanger.3mf
185.1 x 185.1 x 21.0 mm

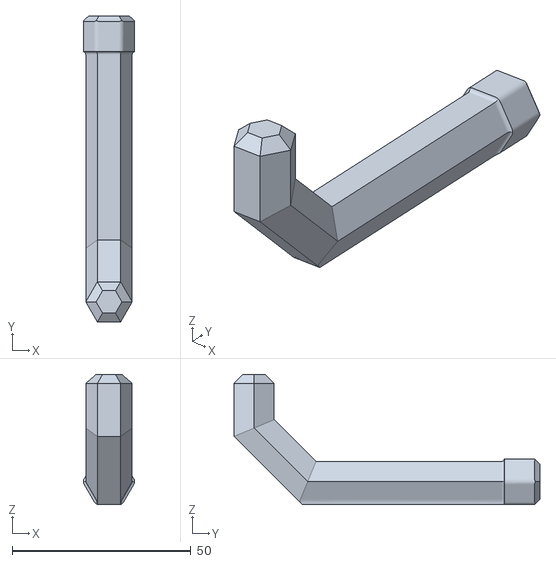
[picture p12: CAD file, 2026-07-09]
models/HSW/Hook Large.stl
14.3 x 85.6 x 36.4

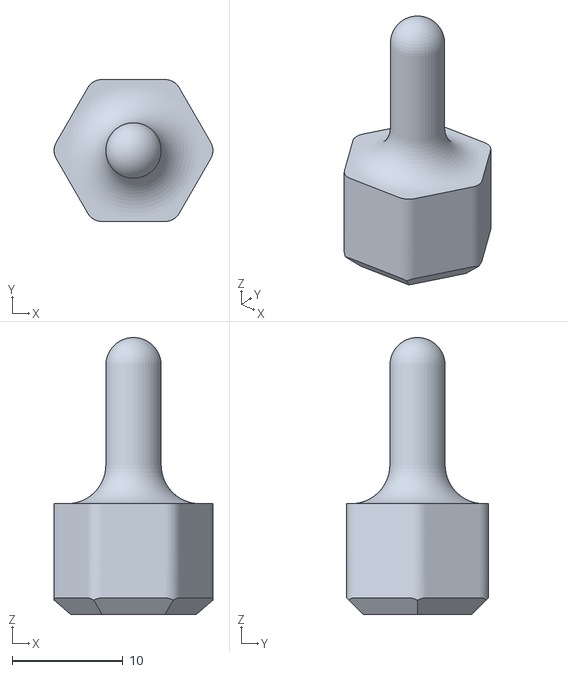
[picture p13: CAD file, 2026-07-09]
models/HSW/Hook Short.stl
14.3 x 12.8 x 25.0

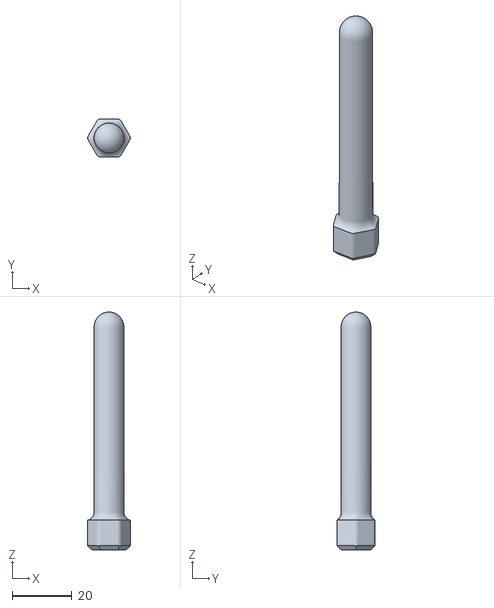
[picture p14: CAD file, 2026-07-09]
models/HSW/Hook Straight.stl
14.3 x 12.8 x 80.0

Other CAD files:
models/HSW/Thick Hanger.3mf
models/HSW/Hook Collection.3mf
models/HSW/Hook Curved.stl
models/HSW/Screwdriver.3mf
models/HSW/Caliper.f3d
models/HSW/Caliper.stl
models/HSW/Hooks.f3d
models/HSW/Pliers.f3d
models/HSW/Pliers.stl
models/HSW/Screwdriver.stl
models/HSW/Screwdrivers.f3d
models/HSW/Small Spool.f3d
models/HSW/Spool Holder.f3d
models/HSW/Template Base Plate.f3d
models/HSW/Template Inserts.f3d
models/HSW/Template Vertical Base Plate.f3d
models/HSW/Thick Hanger.f3d
models/HSW/Thick Hanger.stl
models/HSW/Thin Hanger.f3d
models/HSW/Thin Hanger.stl

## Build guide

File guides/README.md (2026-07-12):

# 3D Printing Concepts, Guides, and Terminology

This area contains information explaining various parts of 3d printing.

This is definitely not comprehensive.

</br></br>

[Hardware](hardware.md) - Printer hardware information

[Filament](filament.md) - Filament information and slicer settings

[Ironing](ironing.md) - Improve print quality with the ironing feature

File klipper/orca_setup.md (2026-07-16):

# Setup Orca With a Klipper Printer

## Overview

You no longer need to export prints to gcode, and transfer them manually.

Not only can you access your printer through the mainsail UI, you can also configure your slicer to connect directly.

Before starting this, you should have:
* Installed Orca Slicer
* Setup your Raspberry Pi with Klipper, Moonraker, and Mainsail
* Flashed your printer with the Klipper firmware
* Confirmed you can reach the printer from the Mainsail UI

</br></br>
If you have not done this yet, [follow the Klipper setup guide](klipper.md)

</br></br>
---
## Add The Printer

###  Moonraker API

The connection between the slicer and printer will use the Moonraker API. This means we need to get an API key to be allowed to connect.

1. Open a web browser
2. Browse to http://your-printer-ip/access/api_key
3. You will get some text like this: `{"result":"xxxxxxxxxx"}`
4. The second part, shown as "xxxxxxx" here, is the API key; Copy this key

</br></br>
> [!WARNING]
>
> API keys are like passwords. You should keep them secret.

</br></br>
### Printer Connection

1. Open Orca Slicer
2. Prepare > Printer
3. Find the **connection** button (it looks like a WiFi symbol)
4. Enter a name for your printer
5. Set The host type to **Moonraker**
6. Set the printer agent to Orca
7. Enter the IP of the printer
8. Enter the API key
9. Click **Test**
10. Click **OK**





</br></br>
If this is all working, when you go to the **Device** tab, you should immediately get access to Mainsail.

</br></br>
---
## Printer Settings

We need to tune the printer settings a bit to get the best out of it.

Click the **edit** button next to the printer (it looks like a pencil).

</br></br>
**Printable Space**

In the _Basic Information_ tab, click the **Set** button next to _Printable area_.

Enter the size of the print bed. For the Ender 3, this is 220mm x 220mm.



</br></br>
**G-Code Flavour**

Still in the _Basic Information_ tab, under the _Advanced_ area, set **G-code flavor** to Klipper.

</br></br>
**Machine G-code**

Refer to [the macros](../macros/README.md) section for information on setting start and end macros.

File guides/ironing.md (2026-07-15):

# Ironing and Top Surface Quality

## Overview

Ironing is used to smooth out the top layer of a print. This adds to a nice finished look on the top layer.

The hot printer nozzle slowly passes over a layer, smoothing out the surface. This uses the nozzle heat remelt plastic ridges while pressing them flat.

This also extrudes a small amount of filament to fill in any gaps or pits in the surface.

Ironing is set in Process > Quality > Ironing.

</br></br>
Some good starting values are:

| Setting | Value |
| --- | --- |
| Ironing Type | All top surfaces or Topmost surface only |
| Pattern | _up to your preference_ |
| Ironing Flow | 10% |
| Ironing line spacing | 0.15mm (75% of the nozzle diameter) |
| Ironing inset | 0.21mm |
| Ironing angle offset | 45° or 90° |
| Ironing Speed | 50mm/s |

</br></br>
To find to optimal values, use a [top surface ironing test](https://www.printables.com/model/1247198-top-surface-ironing-test/files).

This will print at different speeds and fill rates. From there, just decide which settings are best for your printer and filament.

</br></br>
> [!TIP]
> To further tune your top surface, try reducing the _line width_ by about 0.04mm.
>
> The default is 0.40mm, so try 0.36mm.
>
> Find this setting in Quality > Line width.

</br></br>
## Settings

### Ironing Type

This defaults to 'no ironing'. Options are:
* All top surfaces
* Topmost surface only
* All solid layers (this includes the top layer of internal infill)

</br></br>
### Pattern

This is the pattern the hotend moves in while ironing. This will affect the finish of the print. The two options are:
* Rectilinear
* Concentric

</br></br>
### Flow

While ironging, the printer will extrude a small amount of filament to fill in any gaps.

This is a smaller percentage of the normal filament flow.

</br></br>
### Line Spacing

This is the distance between each line during ironing.

This is measures in millimeters, but is calculated as a percentage of the nozzle diameter.

</br></br>
### Inset

This is the distance the extruder will stay away from the edge of the surface. A setting of zero means it will iron all the way to the edge.

However, ironing all the way to the edge can cause overextrusion.

</br></br>
> [!NOTE]
> This is a setting to tinker with, based on the results you want to achieve

</br></br>
### Angle

The angle of ironing. That is, the direction the nozzle travels relative to the underlying lines of the top layer.

This sets how the nozzle cuts across the "grain" of the top layer.

A negative value will disable the angle function entirely.

</br></br>
> [!NOTE]
> Try 45° and 90° to see which you prefer

</br></br>
### Ironing Speed

This is in the Process > Speed > Other layers speed area.

This controls the speed at which the ironing is done. Measured in mm/s.

Usually, slower speeds lead to better results (but longer print times).

</br></br>
Sample Values:

| Profile | Speed |
| --- | --- |
| High quality | 15-30 mm/s  |
| Balanced | 40-60 mm/s  |
| Draft | 70-100 mm/s |

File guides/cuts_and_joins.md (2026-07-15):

# Cutting and Joining Parts

## Overview

With a smaller print bed, there are times that a print needs to be cut into parts and joined later.

In Orca slicer, there is a **cut** tool in the **prepare** tab.

There are two modes:
* Planar
* Dovetail

</br></br>
These can be used for simple cuts, which allows parts to be glued back together.

Alternatively, we can use a dovetail joint, or connectors, to _potentially_ join parts without glue. Or, they can be used as guides, so gluing pieces together is more accurate.

The problem is, printer tolerances mean that we can't just print up some joints. There's a few settings to be tuned.

</br></br>
> [!WARNING]
> This guide assumes that you have already calibrated the tolerance of your printer

</br></br>
> [!NOTE]
> It seems likely that settings mentioned here will vary based on filament, and possibly the number of walls.

</br></br>
---
## Types

### Planar

A planar cut is a straight cut down an object.

</br></br>


</br></br>
If you just want to cut an object up, just use this cut and adjust it's position.

If you want to join the objects you're cutting, you can click **add connectors**.

</br></br>


</br></br>
There are three types of connectors:
* Plug
* Dowel
* Snap

</br></br>


</br></br>
While in this mode, you will see the cross section of your object. Click on that cross section to add connectors.

</br></br>


</br></br>
#### Plug Connectors

The plug connector is a simple part extruding from one side of the cut. The other side of the cut will have a corresponding hole for the plug to be inserted into.

There are two styles available:
* **Prism** - A simple cylinder (shown on the right in the image below)
* **Frustrum** - A tapered cylinger (shown on the left)

</br></br>


</br></br>
There are four shapes for plugs:
* Circle
* Hexagon
* Square
* Triangle

</br></br>


</br></br>
All these shapes support both _prism_ and _frustrum_ types.

</br></br>
> [!TIP]
> Adding connectors will leave holes on one side of the cut. This will likely need supports when printing.
>
> Use the [support trick](supports.md) to make supports easier to remove from the holes.

</br></br>
#### Dowel Connectors

A dowel connector is very similar to a plug. The difference is, both sides of the cut object have a hole. A _dowel_ piece is created as a separate object.

</br></br>


</br></br>
_Prism_ is the only type available for a dowel connector.

All four shapes (circle, hexagon, square, and triangle) are supported for dowels.

</br></br>


</br></br>
#### Snap Connectors

Snap connectors create something that looks like a plug, but it tapered in the middle (called the _bulge_), and has a split down the centre.

These are meant to create a snap fit between the two parts. This requires the material to have a bit of flexibility, so it may not be suitable in all cases.

</br></br>


</br></br>
The type and shape are fixed for the snap connector. However, it does come with a lot of configurable settings.

</br></br>


</br></br>
---
### Dovetail

The dovetail will cut the model, and leave a _dovetail_ joint, just like you [might see in woodworking](https://en.wikipedia.org/wiki/Dovetail_joint).

</br></br>


</br></br>
Here are some settings that I have found to be useful.

For larger dovetails:

| Setting | Value |
| --- | --- |
| Depth | 6.0mm |
| Depth Tolerance | 0.20mm  |
| Width | 20.00mm |
| Width Tolerance | 0.35mm  |
| Flap Angle | 60° |
| Groove Angle | 0° |

</br></br>


</br></br>
For smaller dovetails:

| Setting | Value  |
| --- | --- |
| Depth | 3.00mm |
| Depth Tolerance | 0.19mm |
| Width | 3.00mm |
| Width Tolerance | 0.32mm |
| Flap Angle | 60° |
| Groove Angle | 0° |

</br></br>


</br></br>
These settings will create a tight fit that will generally mean you won't need glue.

For a looser fit, increase the width tolerance a little.

</br></br>
---
## Tuning

Once you perform a cut, that creates two objects. The way the object is cut then becomes part of those objects.

What I'm trying to say is, you can't edit cuts after they're done. This makes tuning these settings a bit of a pain.

</br></br>
The best option is to start a new project in orca, right click the plate, and add a primitive. A cube will do.

Then, make sure all your other settings are typical of a normal print. That is, number of walls, filament type, speed, etc.

</br></br>
Now, cut this object using the settings above. That is, a planar cut with connectors, or a dovetail cut. Slice the objects, print them, and see how they go.

From there, adjust the tolerances to make the fit tighter or looser as needed.

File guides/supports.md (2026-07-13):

# Supports

## Make Supports Easy to Remove

Supports can sometimes be difficult to remove from a print. And when they are removed, they leave broken bits of plastic.

While the fancy people can use a different filament type as a support, the rest of us need another trick.

</br></br>
In the **Process** Area, go to the **Support** tab.

Apply these settings:

| Category | Setting | Value |
| --- | --- | --- |
| Support  | Enable Support | On |
| Support  | Type | Tree (auto) |
| Support  | Style | Tree Slim |
| Advanced | Top Z Distance | 0.3 |
| Advanced | Top interface layers | 3 |

</br></br>
How does this work? It's mainly the two **advanced** settings.

The `top Z distance` is the size of the gap between the top of the support and the part it is supporting.

The default value for this is 0.2mm, but here it's been increased to 0.3mm. This makes the support easier to break off.

</br></br>
The top interface layers refers to how many surface layers the supports have. By default this is 2.

This has been increased to 3 to make the top of the support stronger. This means it's less likely to break up when you remove the support.

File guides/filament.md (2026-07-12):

# Filament

## Adhesiveness Category

Defines how strongly different materials will bond with each other.

Materials are given a category number. Materials with the same category value will bond well, and are considered to be compatible.

This is used in multi-filament printing, and for management of the prime tower. It enables the slicer to determine if a purge or transition tower is required between layers of different materials.

</br></br>
---
## Density

A measurement in grams-per-cubic-centermeter of how dense the material is.

This value is used to estimate how much of the material is needed for a particular print. This is how the estimated weight and cost of the print are calculated.

</br></br>
> [!NOTE]
> Adjusting this does not improve performance or quality.

</br></br>
---
## Shrinkage

As the material cools it may shrink, resulting in the print being smaller than expected.

The shrinkage parameters enable the slicer to scale the model appropriately, so the final product is the correct size.

* PLA does not shrink a lot; About 0.2-0.5%
* PETG, ABS, and Nylon shrink more; About 1-3%

</br></br>
In the filament profile, a percentage is set. When it is set to 100%, the slicer will assume there is no shrinkage at all.

If PLA shrinks 0.5%, set the shrinkage to 99.5%

This is set in two ways, based on the coordinates:
* Shrinkage (XY)
* Shrinkage (Z)

</br></br>
> [!NOTE]
> This setting helps improve tolerance.

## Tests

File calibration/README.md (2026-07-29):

# Calibration Guide

This is my calibration guide.

While it should work on other printers, it assumes an Ender 3 v3 SE, with the Klipper firmware.

</br></br>
---
## Part 1 - Klipper Calibration

Calibration should be performed in this order:

1. [Approximate bed level](bed_level_estimate.md)
2. [Rotation Distance](rotation_distance.md)
3. [Heater PID Tuning](heater_pid.md)
4. [Axis Twist Compensation](axis_twist.md)
5. [Z-Offset](z_offset.md)
6. [Bed Leveling (AKA 'Bed Mesh')](bed_leveling.md)
7. [Resonance Compensation (AKA 'Input Shaper')](resonance_compensation.md)
8. [Pressure Advance](pressure_advance.md)

</br></br>
---
## Part 2 - Slicer Calibration

These are calibrated in the slicer, not in Klipper.

Results will vary for different filaments. Even the same type (eg, PLA) may vary by brand and colour.

</br></br>
Calibrations are found in the calibration menu at the top of the slicer:



</br></br>
Calibration order:

1. Temperature
2. Max Volumetric Speed (Flow Rate)
3. Flow Ratio
4. Retraction
5. Cornering
6. VFA
7. [Tolerance](tolerance.md)

</br></br>
> [!NOTE]
> Some calibrations are skipped here, as they were calibrated already using Klipper

</br></br>
### Temperature

This is to calibrate the temperature of the nozzle, which affects the viscosity of the filament.

This calibration affects quality, bed adhesion, extrustion levels, and stringing.

</br></br>
Calibration > Temperature

Follow the guide here: [Temp Calibration](https://www.orcaslicer.com/wiki/calibration/temp_calib)

</br></br>
---
### Max Volumetric Speed

This is the maximum amount of filament that can be melted and extruded per second.

This represents a physical limit of the hardware and filament. The max volumentric speed is a value we provide that the printer will not exceed.

</br></br>
Calibration > Max Flow Rate

Follow the guide here: [Max Volumetric Speed (FlowRate)](https://www.orcaslicer.com/wiki/calibration/volumetric_speed_calib)

</br></br>
---
### Flow Ratio

This determines how much filament is extruded. This setting affects print Quality.

</br></br>
> [!NOTE]
> There are two ways this calibration can be performed. One is a 2-Pass method, and the other is called YOLO.
>
> The 2-Pass method is considered legacy. Use the 'YOLO (Recommended' method.

</br></br>
Calibration > Flow Ratio > YOLO

Follow the guide here: [Flow Ratio Calibration](https://www.orcaslicer.com/wiki/calibration/flow_ratio_calib)

</br></br>
---
### Retraction

Retraction is where the extruder pulls back the filament (retracts) a little when moving the print head to a new location.

The point of this is to prevent small extrusions (stringing) during non-extruding moves.

This calibration affects print quality (stringing).

</br></br>

Calibration > Retraction

Follow the guide here: [Retraction test](https://www.orcaslicer.com/wiki/calibration/retraction_calib)

</br></br>
For the Ender, use these settings:



</br></br>
---
### Cornering

Cornering is how well the printer handles changes in direction during moves.

This calibration affects quality and accuracy of the prints. This reduces ringing, ghosting, and overshooting.

</br></br>
Calibration > Cornering

Follow the guide here: [Cornering](https://www.orcaslicer.com/wiki/calibration/cornering_calib)

</br></br>
> [!NOTE]
> If you're not experiencing issues with corners, ringing, etc, you may wish to skip this test.

</br></br>
---
### VFA

VFA (Vertical Fine Artifacts) are surface imperfections on walls. These are often caused by mechanical vibrations.

This calibration aims to determine print speeds that trigger these artifacts.

</br></br>
Calibration > VFA

Follow the guide here: [VFA](https://www.orcaslicer.com/wiki/calibration/vfa_calib)

</br></br>
---
## Notes

Z-Offset, Axis twist, and bed leveling should be repeated if the printer is moved or adjusted in any way.

Resonance compensation should be repeated if anything significantly changes the way the printer vibrates. For example, moving the filament spool from the top of the printer to another location.

Orca's calibration guide can be found here: [https://www.orcaslicer.com/wiki/guides/calibration_guide]

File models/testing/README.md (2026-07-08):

# Testing Models

This area contains models that can be used for calibration and testing.

These models come from various places on the internet. I can't remember them all.

| Model | Purpose |
| --- | --- |
| Benchy.3mf | Standard benchy model for testing |
| First Layer Test.3mf | A single layer print to test bed adhesion and Z-axis offset |
| ringing_tower.3mf | For calibrating resonance compensation |
| square_tower.3mf | for calibrating pressure advance |

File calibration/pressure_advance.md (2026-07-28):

# Pressure Advance

This feature is helpful for reducing ooze during non-extrude moves and blobbing during cornering.

Settings may vary for different filaments.

</br></br>
---
## Calibration

### Slicing

Get the square tower print, and add it to the slicer. Either use the 3mf file in the repository, or the stl file here: [https://www.klipper3d.org/prints/square_tower.stl]

| Tab | Setting | Value |
| --- | --- | --- |
| Quality  | Layer height | Coarse (0.3mm) |
| Quality  | Scarf joint seams | Disabled |
| Strength | Infill | 0 |
| Speed | Speed | 100mm/s |
| Speed | Dynamic acceleration | Disabled |

</br></br>
What is a 'coarse' layer height? It just means a thicker than usual layer height.

0.3mm is a suggested value based on a 0.4mm nozzle.

</br></br>
### Running the Calibration

Run these commands to prepare for the print:

```
SET_VELOCITY_LIMIT SQUARE_CORNER_VELOCITY=1 ACCEL=500
```

```
TUNING_TOWER COMMAND=SET_PRESSURE_ADVANCE PARAMETER=ADVANCE START=0 FACTOR=.005
```

Next, start the print.

</br></br>
### Interpreting the Results

The commands above tell klipper to adjust the pressure advance values on each layer of the print. Higher layers have a higher value.

Layers below the ideal value will have blobbing at the corners.

Layers above the ideal value will have more rounded corners, and may have poor extrusion leading up to the corner.

If the print seems to have passed the ideal value, the print can be cancelled.

</br></br>
Use calipers to find the height that has the best quality corners. If in doubt, use the lower values.

Calculate the best pressure advance value with this formula:

```
pressure_advance = <start> + <measured_height> * <factor>
```

The <start> and <factor> values come from the previous `TUNING_TOWER` command. They are '0' and '0.005' respectively.

</br></br>
---
## Configuration

Once the best pressure advance value is known, set it in the `printer.cfg` file:

```ini
[extruder]
pressure_advance = <calculated_value>
```

</br></br>
---
## References

[https://www.klipper3d.org/Pressure_Advance.html]

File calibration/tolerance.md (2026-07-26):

# Tolerance

This refers to how accurate the print jobs are. This is especially important if you are cutting and joining large parts, or are using nuts, bolts, screws, etc, in your prints.

Some tolerance is based around the quality of the printer, which can't really be changes.

Other tolerance issues happen when filament shrinks when cooling.

This calibration aims to determine how much shrinkage occurs, and compensates by scaling some area of the print up.

</br></br>
---
## Filament Compensation

Filament Settings > Filament (Tab) > Basic Information.

In this area there are two settings:
* Shrinkage (XY)
* Shrinkage (Z)

</br></br>
These relate to how much a filament shrinks once it has cooled. For PLA, this is negligable, but other filaments may need tuning.

If you were to print a cube, 10mm x 10mm x 10mm, it ideally should keep those sizes after completely cooling.

If, for example, it changes to 9.6mm wide, and 9.5mm high, then you will need to adjust the filament shrinkage settings.

In this example, the **XY** would be set to 96%, and the **Z** would be set to 95%.

</br></br>
---
## Hole and Contour

The _hole_ is any part that is cut out of a print. The _countour_ is the edge around the outside of the print.

This is shown well on [Bambu Labs Wiki](https://wiki.bambulab.com/en/software/bambu-studio/xy-hole-contour-compensation):

</br></br>


</br></br>
These settings are tuned in the slicer.

Process Settings > Quality (tab) > Precision.

</br></br>
---
### X-Y Hole Compensation

To calibrate this, start a new project in Orca Slicer. Right click on the build plate, and go to _handy models_. Then add **Orca Tolerance Test**.

</br></br>


</br></br>


</br></br>
Now print the model. If the tolerance is good, the hexagonal insert should very easily slide out of the **0.4** hole, and it should fit snugly into the **0** hole.

Also, a **6mm** allan key should fit into the '0' hole.

</br></br>
If this does not happen, the tolerance is off.

If, for example, the allan key fits nicely into the **0.1** hole, then the tolerance is off by about 0.1mm.

Adjust the **X-Y Hole Compensation** setting in the slicer to **0.1**

</br></br>
Now repeat the process. You may need to adjust to smaller values to get it just right.

I found that **0.12** was a good value on my Ender 3, using PLA.

</br></br>
---
### X-Y Contour Compensation

This calibration involved printing a known sized object, and measuring the result.

I used the basic process in [Bambu Labs Wiki](https://wiki.bambulab.com/en/software/bambu-studio/xy-hole-contour-compensation).

</br></br>
Download the [XY Contour Calibration without Calipers](https://makerworld.com/en/models/2172676-xy-contour-calibration-without-calipers#profileId-2356707) model from Maker World.

Even though it says you can do this without calipers, using calipers is better.

</br></br>
Add the STL to Orca Slicer. There's a lot more here than we need, so I recommend slicing a bunch of material off the top, leaving about 15-20 layers.

The result is a 55mm disc.

</br></br>
Print the model, and wait for it to completely cool down. Then measure its width. It should come out to 55mm.

If not, it's time to tune our settings.

Subtract the result you got from 55mm. In my case, it was 54.6mm, so I was left with 0.4mm. Now halve that value. So, 0.2 in my case.

Now go to the Contour Compensation section, and add this value in.

</br></br>


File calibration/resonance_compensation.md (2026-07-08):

# Resonance Compensation

## Overview

This is also known as _input shaping_.

'Ringing' is a surface defect where edges repeat themselves on a printed surface, leaving a subtle 'echo' of the edge.

This is caused by mechanical vibrations in the printer, which is caused by quick changes in the print direction.

Input shaping is where a signal is used to cancel out vibrations.

</br></br>
---
## The 'Ringing Tower'

Download the ringing tower. Either the 3mf in this repository, or the stl file here: [https://www.klipper3d.org/prints/ringing_tower.stl].

</br></br>
### Slicer Setup

Open in Orca. The 3mf should have the correct settings already.

For the stl:

| Parameter | Setting | Location |
| --- | --- | --- |
| Layer height | 0.2mm | Process > Quality |
| Infill | 0% | Process > Strength > Infill |
| Top layers | 0 | Process > Strength > Top/bottom shells |
| Walls loops | 2 | Process > Strength > Walls |
| Outer wall speed | 100mm/sec | Process > Speed > Other layers |
| Min layer time | <= 3s | Material Settings > Cooling > Max fan speed > Layer time |
| Dynamic acceleration | Disabled  | Process > Speed > Aceleration > Normal printing = 0 |
| accel_to_decel | Disabled  | Process > Speed > Aceleration > Enable accel_to_decel |

</br></br>
### Klipper Setup

A few Klipper settings before printing the model.

First, add an `[input_shaper]` section to `printer.cfg`.

Next, check these settings:

| Parameter | Setting | Notes |
| --- | --- | --- |
| square_corner_velocity | 5.0 | This is the default setting |
| minimum_cruise_ratio | Disabled  | Run `SET_VELOCITY_LIMIT MINIMUM_CRUISE_RATIO=0`  |
| Pressure Advance | Disabled  | Run `SET_PRESSURE_ADVANCE ADVANCE=0` |

</br></br>
Run this command: `SET_INPUT_SHAPER SHAPER_FREQ_X=0 SHAPER_FREQ_Y=0`

If this returns 'unknown command', ignore it and move on.

</br></br>
Run this command: `TUNING_TOWER COMMAND=SET_VELOCITY_LIMIT PARAMETER=ACCEL START=1500 STEP_DELTA=500 STEP_HEIGHT=5`

This sets high levels of acceleration to make the ringing effect more pronounced.

</br></br>
### Print the Model

Start printing the model.

If ringing is clearly visible, you can stop the print early. Also, if acceleration is getting too high for the printer, causing excessive shaking and starts skipping steps, stop the print early.

</br></br>
### Interpreting the Results

The front side of the model has a vertical groove.

The back of the print has a large 'X' and 'Y' embossed. These tell us which part of the model is used to calibrate each axis.

Starting with the 'X' area:
1. Ignore the first two 'echos' next to the vertical groove
2. Using a marker, mark the next echo (eg, on the top of the 'wave')
3. Place a second mark several echo's over (horizontally)
4. Count the number of echos between the two marks; Call this _n_ (eg, n = 6 if there are 6 echos)
5. Using calipers, measure the distance between the two marks; Call this _d_ (eg, d = 12.34mm)
6. Get the print speed of the outer walls; In the settings above, this is 100mm/s; Call this _v_.
7. Use the formula below to get the ringing frequency in Hz

```
frequency = v * n / d
```

Using the example values above, the ringing frequency is 100 x 6 / 12.34, or 48.62Hz.

</br></br>
Now, repeat the process for the 'Y' area.

</br></br>
---
## Configuration

### Shaper Settings

With those two values in hand, update the settings in `printer.cfg`.

```ini
[input_shaper]
shaper_freq_x: ...  # X frequency
shaper_freq_y: ...  # Y frequency
```

</br></br>
### Input Shapers

Input shapers are essentially a smoothing algorithm. There are a few to choose from in Klipper, but usually it goes like this:

1. Try the `MZV` shaper first; It's the gentler option
2. If that's not suitable, try the `EI` shaper
3. If that's no good, well you're in interesting territory; You need to find another shaper

</br></br>
To set the shaper, update the settings in `printer.cfg`:

```ini
[input_shaper]
shaper_freq_x: ...  # X frequency
shaper_freq_y: ...  # Y frequency
shaper_type: mzv
```

</br></br>
Now try printing the ring tower again. With these settings there should be no ringing.

If there is still ringing, change shaper and try again.

> [!NOTE]
> Do not enter `SET_INPUT_SHAPER SHAPER_FREQ_X=0 SHAPER_FREQ_Y=0` this time.
> This sets the x and y frequency to zero. We want to use the values in the config file.

</br></br>
---
## References

[https://www.klipper3d.org/Resonance_Compensation.html]

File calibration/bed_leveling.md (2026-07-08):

# Bed Leveling

## Goal

The goal of bed leveling is to make sure the print nozzle remains exactly the expected distance from the print bed.

The height of the nozzle from the bed is the Z-axis. For good quality prints, the Z-axis should be accurate to about 0.025mm.

The way this is achieved will depend on the model of printer. Some have automatic bed leveling, others use adjustment screws (this is called bed tramming).

</br></br>
---
## Calibration

Before starting:
1. Preheat the bed to normal temp
2. Preheat the extruder to a normal temp

In the mainsail UI, you can go to the 'heightmap' tab, and calibrate the bed mesh from there. Once it is done, you can also save it as a profile to be used later.

Alternatively, you can run the `BED_MESH_CALIBRATE` command, which effectively does the same thing.

This profile can now be loaded before print jobs start.

</br></br>
---
## Adaptive Calibration

You can aqlso use a macro that runs at the start of each print. This runs a command like `BED_MESH_CALIBRATE ADAPTIVE=1`.

This runs the same test, but it probes the area that will be used by the print job.

This is good, but will take longer for the print to start.

</br></br>
---
## References

[https://www.klipper3d.org/Bed_Level.html]

[https://www.klipper3d.org/Probe_Calibrate.html]

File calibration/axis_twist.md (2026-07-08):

# Axis Twist Compensation

## What is it?

Some printers, including the Ender 3, have a small twist in the X rail, which can skew probe results.

This guide is about compensating for this twist.

### Location Bias

Some probes have a bias that corrupts the results of probing at certain locations.

As the print head moves along a rail, a slight twist in the rail causes the probe to be slightly off.

</br></br>
---
## Calibration

### Part 1 - Configuration

1. Edit the `printer.cfg` file
2. Check if there is a section called `[axis_twist_compensation]`
3. If it is not there, create it and save/restart

```ini
[axis_twist_compensation]
calibrate_start_x: 20
calibrate_end_x: 200
calibrate_y: 110
```

These settings define the calibration bounds. That is, the safe X and Y boundaries to use during the test.

The values above assume a 220x220mm bed. 20mm is left of the margins of this area for the probe.

</br></br>
### Part 2 - Calibration

1. Preheat the bed and the hot end
2. Clean the nozzle so there's no filament there
3. Home the print head (`G28`)
4. Run `AXIS_TWIST_COMPENSATION_CALIBRATE`
   This will probe at several places on the print bed
   For each one, a manual probe window will pop up
5. Add a sheet of paper to the bed
6. Adjust the height of the probe until the nozzle touches the paper
7. Fine tune until there is some friction when moving the paper around
8. Click accept
9. Repeat for remaining points
   There should be three points in total; Left, centre, and right
10. Run `SAVE_CONFIG`

</br></br>
---
## References

[https://www.klipper3d.org/Axis_Twist_Compensation.html]

[https://www.klipper3d.org/Probe_Calibrate.html#location-bias-check]

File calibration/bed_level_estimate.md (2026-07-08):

# Bed Level Estimate

Bed leveling happens later in the process, but I have found that it is worth getting an estimate on how level it is early on.

If you get the bed approximately correct now, fine tuning will be better later.

</br></br>
---
## Process

1. Preheat the bed to normal temp
2. Home the print head
3. In mainsail, go to the 'heightmap' tab, and click calibrate

Alternatively you can use the `BED_MESH_CALIBRATE` command.

</br></br>
In mainsail, we will get a nice visual to show us how level the bed is.

In some cases like this one, the bed level is way out. The range is very large (0.542mm in this case).





</br></br>
We can leave it as it is and let software handle it. However, this is not always ideal, as the software was really only meant for fine tuning.

This needs manual leveling, which usually means adding spacers under the print bed, or changing them.

</br></br>
In this case, the front left side is too high. I did this:

1. Raised the print head up, so it wont be in the way
2. Cooled the printer down, and turned it off
3. Removed the print bed
4. Took out the front left spacer, and sanded it down (only very slightly)

</br></br>
I ended up getting the corners to be similar heights.



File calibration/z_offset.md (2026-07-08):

# Z Offset

## Goal

The nozzle of the print head should be just the right distance away from the print bed.

If it is too close, it will scrape away existing printed material. If it's too far away, the filament will not stick to the bed correctly.

</br></br>
---
## Calibration

### The Paper Test

This is almost identical to the axis twist compensation step. The difference is, it is only done in one place.

1. Make sure the nozzle is clean
   Remove any bits of filament
   This may require preheating the nozzle to clean it up
3. Home the printer (`G28`)
4. Run `PROBE_CALIBRATE`
   The print head will probe a few times
   A window will appear with manual tuning information
6. Place a piece of paper on the print bed, below the print head
7. Using the manual probe buttons, adjust the height of the print head
   Moving the paper around should have a small amount of friction
8. When you have the right results, click 'accept'
9. Run 'SAVE_CONFIG'

</br></br>
### Accuracy Check

Next, run a repeatibility check. This runs the probe check several times and records values.

1. Home the print head
2. Run 'PROBE_ACCURACY'

Ideally, the max and min values will be the same. However, this isn't usual, as there's always some deviation.

The range value should be 0.025mm or less.

</br></br>
## References

[https://www.klipper3d.org/Bed_Level.html]

[https://www.klipper3d.org/Probe_Calibrate.html]

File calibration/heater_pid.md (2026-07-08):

# Heater PID Calibration

## What is it?

PID is Proportional, Integral, and Derivative. It refers to the steps a controller takes to maintain a steady state of some function.

In this case, the function is the temperature of the bed and the extruder.

The purpose of tuning this is to ensure that the print bed and hot end are heated in the least time possible, and that the temperature is maintained.

</br></br>
---
## How it Works

The Klipper firmware heats and cools the print bed and extruder a few times and measures results.

</br></br>
---
## Calibration

This can be run as Klipper commands, but it's easier to use the built-in macros.

1. Home the print head
2. Dashboard > Macros area
3. Click the drop down next to 'PID BED'
4. Enter the temperature you typically use, such as 60
5. Wait for ages
   Must be patient, this takes a while, 15min or so
   On the temperature graph you will see the print bed heating up and cooling repeatedly
   When it's done, some new values will appear in the console
6. Run the macro for 'PID EXTRUDER', using your typical temperature
   This is much faster to run
   New values will appear in the console when done
7. Save the new configuration

### Commands

If the macros aren't available, you can run these commands:

</br></br>
Calibrate the bed:
```
PID_CALIBRATE HEATER=heater_bed TARGET=60
```

</br></br>
Calibrate the extruder:
```
PID_CALIBRATE HEATER=extruder TARGET=220
```

</br></br>
Save the config:
```
SAVE_CONFIG
```

</br></br>
---
## References
https://www.obico.io/blog/klipper-pid-tuning/

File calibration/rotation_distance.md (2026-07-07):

# Rotation Distance Calibration

## What Is It?

Rotation distance is the length of filament that is extruded with one full rotation of the extruder's stepper motor.

Stepper motors have a number of steps within each full rotation.
Most stepper motors in a 3d printer have 200 full steps per rotation, and 16 microsteps per full step.

The number of steps per millimeter of extruded filament depends on the manufacturer.

</br></br>
### Stock Ender 3 Values

| Stepper | Full Steps | Micro Steps | Steps per mm | Rotation Distance |
| --- | --- | --- | --- | --- |
| NEMA 17 | 200 | 16 | 93.0 | 7.663 |

</br></br>
### Calculation

The typical formula for this is:

`rotation_distance = <full_steps_per_rotation> * <microsteps> / <steps_per_mm>`

However, this comes out at 34.408, which is wildly incorrect.

This is because the extruder has a gearbox with a ratio of 4.5:1 (or something like that).

</br></br>
### Configuration

The rotation distance is stored in `printer.cfg`:

```ini
[extruder]
rotation_distance: 7.663
```

</br></br>
---
## Calibration

### Overview

The main idea is this:
1. Attempt to print a fixed length of filament
2. Measure how much was actually printed
3. If these don't match, adjust the rotation distance

</br></br>
### Procedure - Part 1

1. Heat the extruder to the value you typically use (eg, 200-220°); The bed does not need preheating
2. Measure exactly 120mm from the top of the filament intake
3. Use a marker or pen to mark this point on the filament (a lighter colour filament might help with this)
4. Send g-code commands to the printer, to slowly extrude 100mm of filament (code is below)
5. Meaure the distance from the top of the filament intake to the mark

</br></br>
```gcode
M83            ; Set relative mode
M109 S220      ; Preheat the extruder to 220, and wait for this to complete
G1 E100 F50    ; Extrude 100mm of filament at 50mm/min
```

</br></br>
If the distance from the intake to the mark is 20mm, then your job is done. The rotation distance is set correctly.

If not, move on to part 2.

</br></br>
### Procedure - Part 2

We need to calculate a new rotation distance.

First, get the current setting from `printer.cfg`. This seems to be 7.663 by default (you should double check this).

Next, determine how much filament was actually extruded. To do this, subtract the remaining distance from 120mm.
For example, if there's 21mm left, the printer actually extruded 99mm of filament.

Using this formula, determine the new rotation distance:

```
rotation distance = current rotation distance x actual extruded length / 100
```

</br></br>
Now you have the new value, update `printer.cfg` with the new value.

I would recommend running the test again now to confirm the value is working as expected.

</br></br>
---
## References

[https://www.klipper3d.org/Rotation_Distance.html]

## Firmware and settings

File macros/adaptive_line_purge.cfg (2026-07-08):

#   Adaptive Line Purge Macro (Modified from https://github.com/kyleisah/Klipper-Adaptive-Meshing-Purging)

[gcode_macro ADAPTIVE_LINE_PURGE]
variable_purge_height: 0.8  # Z position of nozzle during purge, default is 0.8 mm.
variable_tip_distance: 4    # Distance in mm between tip of filament and nozzle before purge. Should be similar to PRINT_END final retract amount.
variable_purge_margin: 10   # Distance the purge will be in front of the print area, default is 10 mm.
variable_purge_amount: 20   # Amount of filament in mm to be purged prior to printing.
variable_flow_rate: 12      # Flow rate of purge in mm3/s. Default is 12.
gcode:
    {% set travel_speed = printer.toolhead.max_velocity * 60 %}
    {% set cross_section = printer.configfile.settings.extruder.max_extrude_cross_section | float %}
    
    {% set RETRACT = 'G10' if printer.firmware_retraction is defined else 'G1 E-0.5 F2100' %}
    {% set UNRETRACT = 'G11' if printer.firmware_retraction is defined else 'G1 E0.5 F2100' %}

    {% set all_points = printer.exclude_object.objects | map(attribute='polygon') | sum(start=[]) %}    ; Get all object points
    {% set x_min = (all_points | map(attribute=0) | min | default(0)) %}                                ; Object x min
    {% set x_max = (all_points | map(attribute=0) | max | default(0)) %}                                ; Object x max
    {% set y_min = (all_points | map(attribute=1) | min | default(0)) %}                                ; Object y min
    {% set y_max = (all_points | map(attribute=1) | max | default(0)) %}                                ; Object y max
    
    {% set x_center = ([((x_max + x_min) / 2) - (purge_amount / 2), 0] | max) %}                        ; Create center point of purge line relative to print on X axis
    {% set y_center = ([((y_max + y_min) / 2) - (purge_amount / 2), 0] | max) %}                        ; Create center point of purge line relative to print on Y axis

    {% set x_origin = ([x_min - purge_margin, 0] | max) %}                                              ; Add margin to x min, compare to 0, and choose the larger
    {% set y_origin = ([y_min - purge_margin, 0] | max) %}                                              ; Add margin to y min, compare to 0, and choose the larger

	{% set x_max_bed = printer.toolhead.axis_maximum.x %}										; Avoid passing print bed maximum
	{% set y_max_bed = printer.toolhead.axis_maximum.y %}										; Avoid passing print bed maximum

    # Calculate purge speed
    {% set purge_move_speed = (flow_rate / 5.0) * 60 | float %}

    {% if cross_section < 5 %}
        {action_respond_info("[Extruder] max_extrude_cross_section is insufficient for purge. Set it to 5 or greater. Purge skipped.")}
    {% else %}
        SAVE_GCODE_STATE NAME=prepurge_state                                                    ; Create gcode state

        G92 E0                                                                                  ; Reset extruder
        G0 F{travel_speed}                                                                      ; Set travel speed
        G90                                                                                     ; Absolute positioning
        ;G0 X{x_center if y_origin > 0 else x_origin} Y{y_origin if y_origin > 0 else y_center}  ; Move to purge position
        G0 X{[x_center if y_origin > 0 else x_origin, x_max_bed - 2] | min} Y{[y_origin if y_origin > 0 else y_center, y_max_bed - 2] | min}  ; Move to purge position (with bed size fix)
        G0 Z{purge_height}                                                                      ; Move to purge Z height
        M83                                                                                     ; Relative extrusion mode
        G1 E{tip_distance} F{purge_move_speed}                                                  ; Move filament tip

        {% if y_origin > 0 %}                                                                   		; If there's room on Y, purge along X axis in front of print area
            ;G1 X{x_center + purge_amount} E{purge_amount} F{purge_move_speed}                  		 ; Purge line
            G1 X{[x_center + purge_amount, x_max_bed - 2] | min} E{purge_amount} F{purge_move_speed}	; Purge line (with bed size fix)
            {RETRACT}                                                                           		; Retract
            ;G0 X{x_center + purge_amount + 10} F{travel_speed}                                 		 ; Rapid move to break string
            G0 X{[x_center + purge_amount + 10, x_max_bed - 2] | min} F{travel_speed}  					; Rapid move to break string (with bed size fix)
        {% else %}                                                                              		; If there's room on X, purge along Y axis to the left of print area
            ;G1 Y{y_center + purge_amount} E{purge_amount} F{purge_move_speed}                  		 ; Purge line
            G1 Y{[y_center + purge_amount, y_max_bed - 2] | min} E{purge_amount} F{purge_move_speed}	; Purge line (with bed size fix)
            {RETRACT}                                                                           		; Retract
            ;G0 Y{y_center + purge_amount + 10} F{travel_speed}                                 		 ; Rapid move to break string
            G0 Y{[y_center + purge_amount + 10, y_max_bed - 2] | min} F{travel_speed}  					; Rapid move to break string (with bed size fix)
        {% endif %}
        
        G0 Z{purge_height * 2} F{travel_speed}                                                  ; Z hop
        {UNRETRACT}                                                                             ; Unretract, Prepeare For Extrusion
        G92 E0                                                                                  ; Reset extruder distance
        M82                                                                                     ; Absolute extrusion mode

        RESTORE_GCODE_STATE NAME=prepurge_state                                                 ; Restore gcode state
    {% endif %}

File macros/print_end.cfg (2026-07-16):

[gcode_macro END_PRINT]
gcode:
    {% set z_safe = [printer.toolhead.position.z + 20,
                     printer.toolhead.axis_maximum.z - 2] | min %}

    M140 S0 					; Turn off bed
    M104 S0 					; Turn off nozzle
    M107                        ; part fan off
    
    G91 						; Relative positioning
    G1 E-4 F2700                ; retract (matches ADAPTIVE_LINE_PURGE tip_distance)
    G90 						; Absolute positioning
    G1 Z{z_safe} F1200          ; lift, clamped to max Z
    G1 X0 Y220 F3000 			; Present the finished print by moving bed forward

    BED_MESH_CLEAR
    M84 						; Disable steppers

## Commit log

2026-07-09 Create Template Base Plate.md
2026-07-09 Create Template Inserts.md
2026-07-09 Create Template Vertical Base Plate.md
